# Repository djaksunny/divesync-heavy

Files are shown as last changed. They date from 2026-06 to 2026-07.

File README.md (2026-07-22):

# DiveSync Heavy

An autonomous underwater depth-control vehicle built around an ESP32 and MS5837 depth sensor, using a linear actuator syringe mechanism (0–100mm stroke) for buoyancy-based depth control. This repo contains the firmware, hardware design files, and control software — including PID and reinforcement learning (TD3) controllers — developed as part of ongoing research under Umar.

## Hardware Overview

- **Depth sensing:** MS5837 pressure/depth sensor
- **Actuation:** Linear actuator-driven syringe mechanism, 0–100mm stroke, adjusts buoyancy by changing displaced volume
- **Compute:** ESP32, communicating over USB serial (115200 baud) with a host machine running the Python control stack
- **Control loop:** 20Hz telemetry/state/actuator loop, with an inner PID stabilizing actuator position and an outer controller (PID / BC / RL) setting the depth-tracking target

Full schematics, PCB layout, and BOM are under `/eda`.

## Repository Structure

```
divesync-heavy/
├── data/                     # Raw experiment logs, grouped by hardware/software version -- see "Experiment Data" below
├── eda/                      # KiCad schematic, PCB, BOM, and exported schematic PDF
├── firmware/                 # ESP32 firmware (PlatformIO project)
├── python/
│   ├── controllers/
│   │   ├── inner.py           # Inner PID loop — actuator position control
│   │   ├── manual.py          # Gamepad/keyboard manual control
│   │   ├── pid.py             # Outer PID depth controller
│   │   ├── rl.py              # TD3 (fully online) depth controller
│   │   └── waveform.py        # Square-wave setpoint/actuator generator
│   ├── core/
│   │   ├── experiment.py      # Experiment setup, handshake, state machine
│   │   ├── logger.py          # CSV logging (raw/processed/state)
│   │   ├── merger.py          # Merges state + processed CSVs into training_data.csv
│   │   ├── processor.py       # Depth filtering, actuator unit conversion
│   │   ├── serial_manager.py  # Serial I/O with the ESP32
│   │   ├── state.py           # Computes depth error, filtered velocity
│   │   └── telemetry.py       # Raw serial line parsing
│   ├── ml/
│   │   ├── reward.py              # TD3 reward function
│   │   ├── td3_env_spec.py        # Gym shape-declaration env for SB3 (also defines the fixed obs-normalization bounds)
│   │   ├── td3_model.zip          # Actively-training TD3 model (updated after each RL dive)
│   │   └── td3_replay_buffer.pkl  # Persisted replay buffer across dives
│   └── visualization/
│       ├── display.py         # Live Tkinter depth/setpoint/error display
│       └── plotter.py         # Post-dive matplotlib plotting (depth/actuator/motor voltage)
├── results/
│   ├── divesync-heavy-v1-results/   # Behavior cloning, cascaded PID, step response, sysid plots
│   ├── divesync-heavy-v2-results/   # Behavior cloning, cascaded PID (fixed/variable), RL (fixed/variable)
│   └── divesync-heavy-v3-results/   # Fully-online RL: early / failure / converged
├── main.py                    # Experiment entry point / main control loop
├── requirements.txt
├── .gitignore
└── README.md
```

## Control Strategies

Two outer-loop control strategies were implemented and compared:

1. **PID** — classical outer-loop depth PID feeding actuator position setpoints to the inner PID. Cascaded/nested PID across both loops was tested and found unstable (~99% of trials); the current architecture uses a single outer PID plus a fixed inner actuator-position PID instead.
2. **Reinforcement Learning (TD3)** — an off-policy, deterministic actor-critic algorithm (Twin Delayed DDPG), trained fully online on real hardware from a randomly-initialized actor and critics (no warm-start). Chosen over SAC/PPO/DDPG because its replay buffer suits the limited real-hardware sample budget, and its twin critics counter the Q-value overestimation that made vanilla DDPG unreliable.

### TD3 Implementation Notes

- Built on `stable_baselines3` (Gymnasium 1.3.0 / SB3 2.9.0), with a shape-only `DiveSyncEnvSpec` env used purely to satisfy SB3's constructor — no vectorized-env training loop is used. `main.py`'s own 20Hz loop *is* the environment loop; each dive is treated as one training episode.
- State inputs to the actor are normalized using the fixed bounds declared in `DiveSyncEnvSpec` (`OBS_LOW`/`OBS_HIGH`), not a data-fitted scaler.
- The reward function combines a depth-tracking error penalty, a velocity-damping penalty, and a smooth exponential barrier discouraging surfacing (and, in later iterations, an analogous barrier for the tank floor and an action-delta smoothness penalty).
- Both online (small periodic updates during a dive) and end-of-dive (`finalize()`, larger update) training were implemented; see **Known Issues** below regarding online training stability.
- Reward isn't logged during a dive. `python/reward_backfill.py` (gitignored, not part of the tracked pipeline) computes it after the fact from a run's `state.csv` (`depth_error_m`, `velocity_mps`) using the weights currently defined in `controllers/rl.py`, across every RL experiment under `data/` at once, writing a gitignored `reward.csv` / `reward_plot.png` per folder. Intent going forward is for `visualization/plotter.py` to compute this the same way but on the fly for a single experiment, rather than relying on a separate batch pass — not wired up yet.

## Running an Experiment

```bash
pip install -r requirements.txt
python main.py
```

You'll be prompted for:
- **Control mode:** `manual` / `pid` / `rl` / `sysid`
- **Experiment duration** (seconds)
- **Notes** (optional, stored in `metadata.json`)
- **COM port** for the ESP32

Each run creates a timestamped folder under `data/` containing `raw.csv`, `processed.csv`, `state.csv`, `boot.txt`, and `metadata.json`. After the experiment ends, `training_data.csv` is generated (merging `state.csv` and `processed.csv`), and a results plot is shown automatically if `processed.csv` exists.

The first `rl`-mode run initializes a fresh TD3 model (random actor + critics) since there is no warm-start; `python/ml/td3_model.zip` and `td3_replay_buffer.pkl` are created after `finalize()` and reused/extended on subsequent RL dives.

## Known Issues / Future Work

- **Online (mid-dive) training instability:** periodic training updates during a dive were found to occasionally collapse the policy into a degenerate constant-action output, likely due to the critic training on too little, too-correlated data early in a dive. Online training is currently disabled by default (`online_gradient_steps=0`); all TD3 updates happen in `finalize()`, once per dive. This was directly reproduced on the first fully-online (no warm-start) dive: the policy overshot to the tank floor, recovered, then froze at a near-constant near-minimum actuator output for the remaining ~9 minutes of a ~11-minute dive despite a large, persistent tracking error. `RLController` now has a `random_warmup_decisions` phase (default 50 decisions, ~50s) where actions are sampled randomly (still delta-clamped for hardware safety) instead of drawn from the untrained actor, so the critic sees diverse transitions before any training happens.
- **Reward scale sensitivity:** TD3 training was found to be highly sensitive to reward term magnitudes — a ~40x increase in one reward weight relative to another was sufficient to destabilize training into bang-bang actuator behavior. Current weights are tuned empirically; a more principled reward-normalization approach is a natural next step.
- **Residual steady-state tracking error:** the current TD3 policy shows a repeatable damped-oscillation response to setpoint changes, converging to a small but consistent depth offset rather than exact tracking. Believed limited primarily by the small amount of real-dive training data available; a larger and more diverse replay buffer (more dives, more setpoint variety) is the most likely path to improvement.

## Experiment Data

Raw experiment logs under `data/`, grouped to match the hardware/software progression documented in `/results`. Each leaf folder is one experiment run (`YYYYMMDD-HHMMSS`), containing `raw.csv`, `processed.csv`, `state.csv`, `boot.txt`, `metadata.json`, and (once merged) `training_data.csv`.

### `divesync-heavy-v1-data/` (2026-07-06 -- 2026-07-09, 14 dives)

Earliest hardware iteration (50mm actuator stroke). Manual piloting, initial PID characterization, step-response/system-ID runs, and the first behavior-cloning + BC-warmstarted-RL attempts. Corresponds to `results/divesync-heavy-v1-results/`.

### `divesync-heavy-v2-data/` (2026-07-10, 2026-07-14, 31 dives)

100mm actuator stroke. Manual piloting for BC training data, PID validation (fixed/variable setpoint), and BC-pretraining-warmstarted TD3 -- the warmstart approach later found to underperform and replaced in v3. Corresponds to `results/divesync-heavy-v2-results/`.

### `divesync-heavy-v3-data/` -- fully-online TD3, no BC warm-start

The BC/warmstart pipeline was removed; TD3 trains entirely online from real dives from here on. Corresponds to `results/divesync-heavy-v3-results/` (reinforcement-learning-early/failure/converged). Split into three subfolders:

- **`pid-validation/`** (2026-07-16, 11 dives) -- pure PID control-mode dives, re-validating the classical baseline on this hardware revision before RL work resumed.
- **`pre-swap/`** (2026-07-17, 23 dives) -- first fully-online TD3 dives on this hardware. Includes the full progression from cold-start collapse through the stuck-recovery and velocity-penalty fixes; best sustained result is `20260717-161502` (81% of samples within 0.05m of setpoint over a 10-minute dive).
- **`post-swap/`** (2026-07-21 -- 2026-07-22, 15 dives) -- after the actuator/buoyancy device was physically swapped, changing the depth dynamics enough to require a model reset (the pre-swap model/replay buffer no longer matched reality -- see `divesync-heavy-v3-data-incomplete-runs/README` for how that was diagnosed). Training restarted fully online on this dataset, converging faster than the original cold start since the warmup/stuck-recovery/reward fixes were already in place.

**Note for reuse:** `pre-swap` and `post-swap` reflect two physically different dynamical systems (same v3 software/methodology, different hardware buoyancy characteristics). Don't pool them for a single tracking-accuracy statistic without accounting for that split.

### `divesync-heavy-v3-data-incomplete-runs/`

Crashed/aborted experiments with no meaningful data (empty or header-only CSVs, no `metadata.json`) -- kept rather than deleted in case they're ever useful for debugging, but excluded from all of the above.

## Results

Comparison plots (behavior cloning, cascaded/fixed/variable PID, fixed/variable-setpoint RL, system identification, step response) are in `/results` and `/results/divesync-heavy-v1-results`.

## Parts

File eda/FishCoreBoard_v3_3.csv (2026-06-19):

Reference | Value | Footprint | Qty | DNP | Label | Part
C1,C3 | 100nF | Capacitor_SMD:C_1206_3216Metric | 2 |  |  | C1206C104K4RAC7800
C2,C4,C5,C7 | 10uF | Capacitor_SMD:C_1206_3216Metric | 4 |  |  | C1206C106K4RAC7800
C6,C12 | 220uF | Capacitor_SMD:CP_Elec_6.3x4.5,Capacitor_SMD:C_1206_3216Metric | 2 |  |  | A768EB476M1ELAE042,C1206C106K4RAC7800
C9 | 470uF | Capacitor_SMD:CP_Elec_6.3x4.5 | 1 |  |  | 875585345004
C10,C11 | 47uF | Capacitor_SMD:CP_Elec_6.3x4.5 | 2 |  |  | A768EB476M1ELAE042
D13 | B340AE-13 | Diode_SMD:D_SMA | 1 |  |  | B340AE-13
J1,J3,J4 | B2B_XH | Connector_JST:JST_XH_B2B-XH-A_1x02_P2.50mm_Vertical | 3 |  | - PWR +,MOT,SW | B2B-XH-A
J2 | Conn_01x05_Pin | Connector_JST:JST_XH_B5B-XH-A_1x05_P2.50mm_Vertical | 1 |  | SYG_ACT | B5B-XH-A
J5 | Conn_01x03_Pin | Connector_JST:JST_XH_B3B-XH-A_1x03_P2.50mm_Vertical | 1 |  | SERVO | B3B-XH-A
J6 | BM04BGHS | Connector_JST:JST_GH_BM04B-GHS-TBT_1x04-1MP_P1.25mm_Vertical | 1 |  | BAR02 | BM04B-GHS-TBT
J7 | Conn_01x04_Pin | Connector_JST:JST_PH_B4B-PH-K_1x04_P2.00mm_Vertical | 1 |  | + R T - | B4B-PH-K
L1 | 68uH | Inductor_SMD:L_Coilcraft_MSS1048-XXX | 1 |  |  | MSS1048-683MLC
R1,R2,R4,R6 | 2K2 | Resistor_SMD:R_1206_3216Metric | 4 |  |  | RMCF1206JT2K20
R3 | 4K7 | Resistor_SMD:R_1206_3216Metric | 1 |  |  | RMCF1206JT4K70
R5 | 1K5 | Resistor_SMD:R_1206_3216Metric | 1 |  |  | RMCF1206JT1K50
RV1 | R_Potentiometer | Potentiometer_SMD:Potentiometer_Bourns_3214J_Horizontal | 1 |  |  | 3314J-1-103E
U1,U3 | DRV8251ADDAR | Umar_Library:SOIC8_DDA_TEX | 2 |  |  | DRV8251ADDAR
U2 | ESP32-C3-DEVKITC-02 | Umar_Library:XCVR_ESP32-C3-DEVKITC-02 | 1 |  |  | ESP32-C3-DEVKITC-02
U5 | AMS1117-3.3 | Package_TO_SOT_SMD:SOT-223-3_TabPin2 | 1 |  |  | AMS1117-3.3
U6 | LM2596S-ADJ | Package_TO_SOT_SMD:TO-263-5_TabPin3 | 1 |  |  | LM2596S-ADJ/NOPB
U7 | AMS1117-5.0 | Package_TO_SOT_SMD:SOT-223-3_TabPin2 | 1 |  |  | AMS1117-5.0

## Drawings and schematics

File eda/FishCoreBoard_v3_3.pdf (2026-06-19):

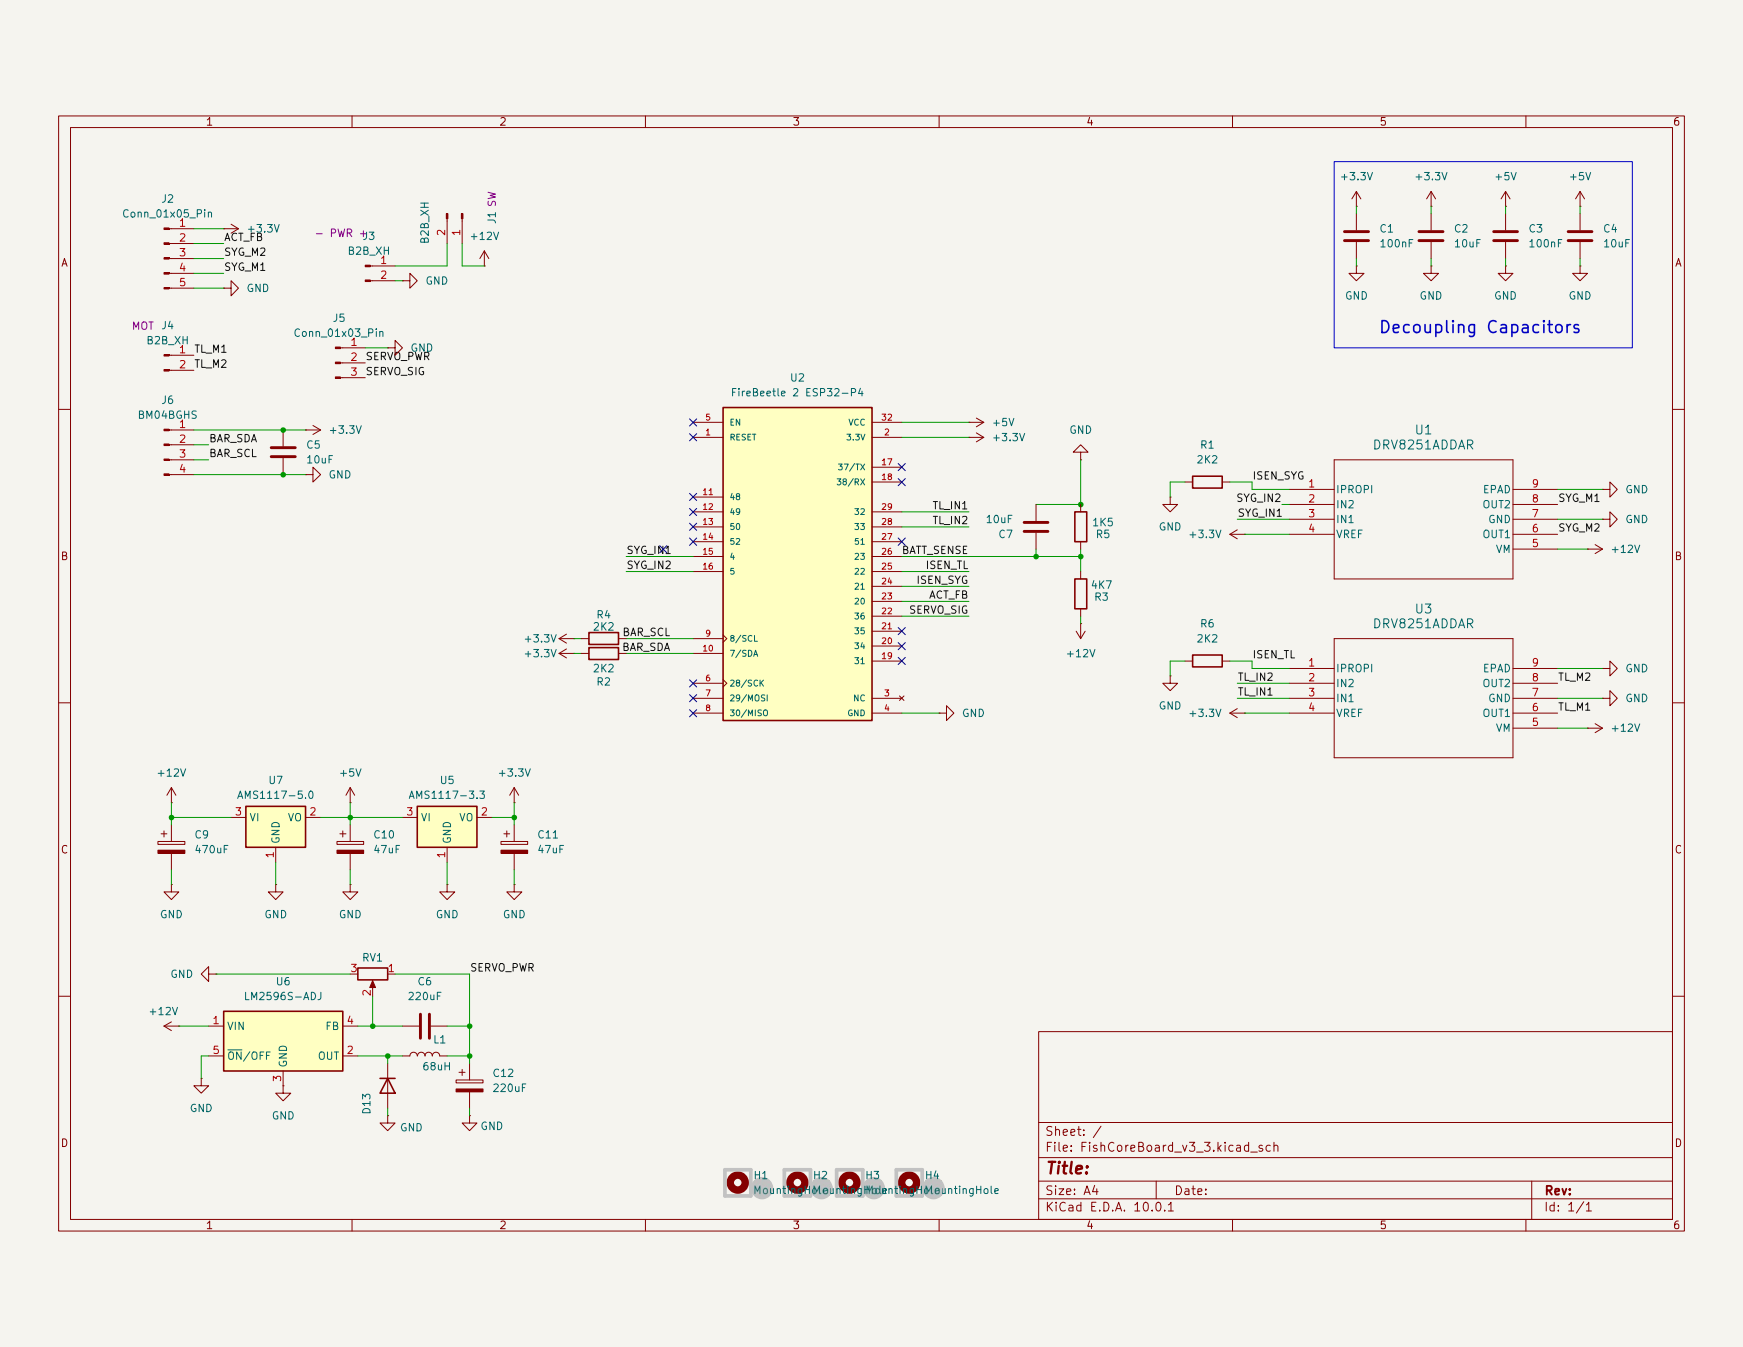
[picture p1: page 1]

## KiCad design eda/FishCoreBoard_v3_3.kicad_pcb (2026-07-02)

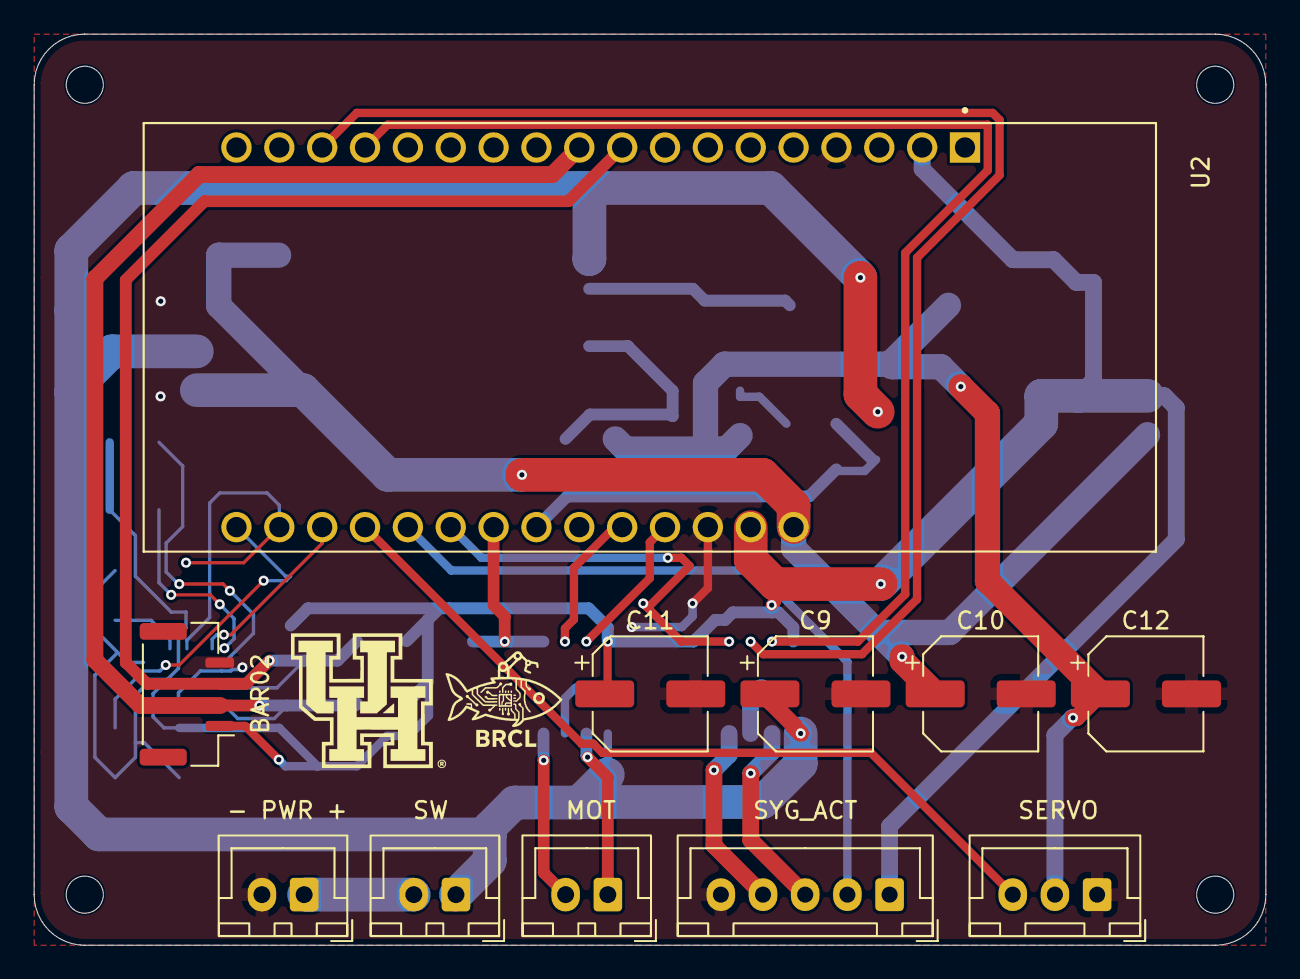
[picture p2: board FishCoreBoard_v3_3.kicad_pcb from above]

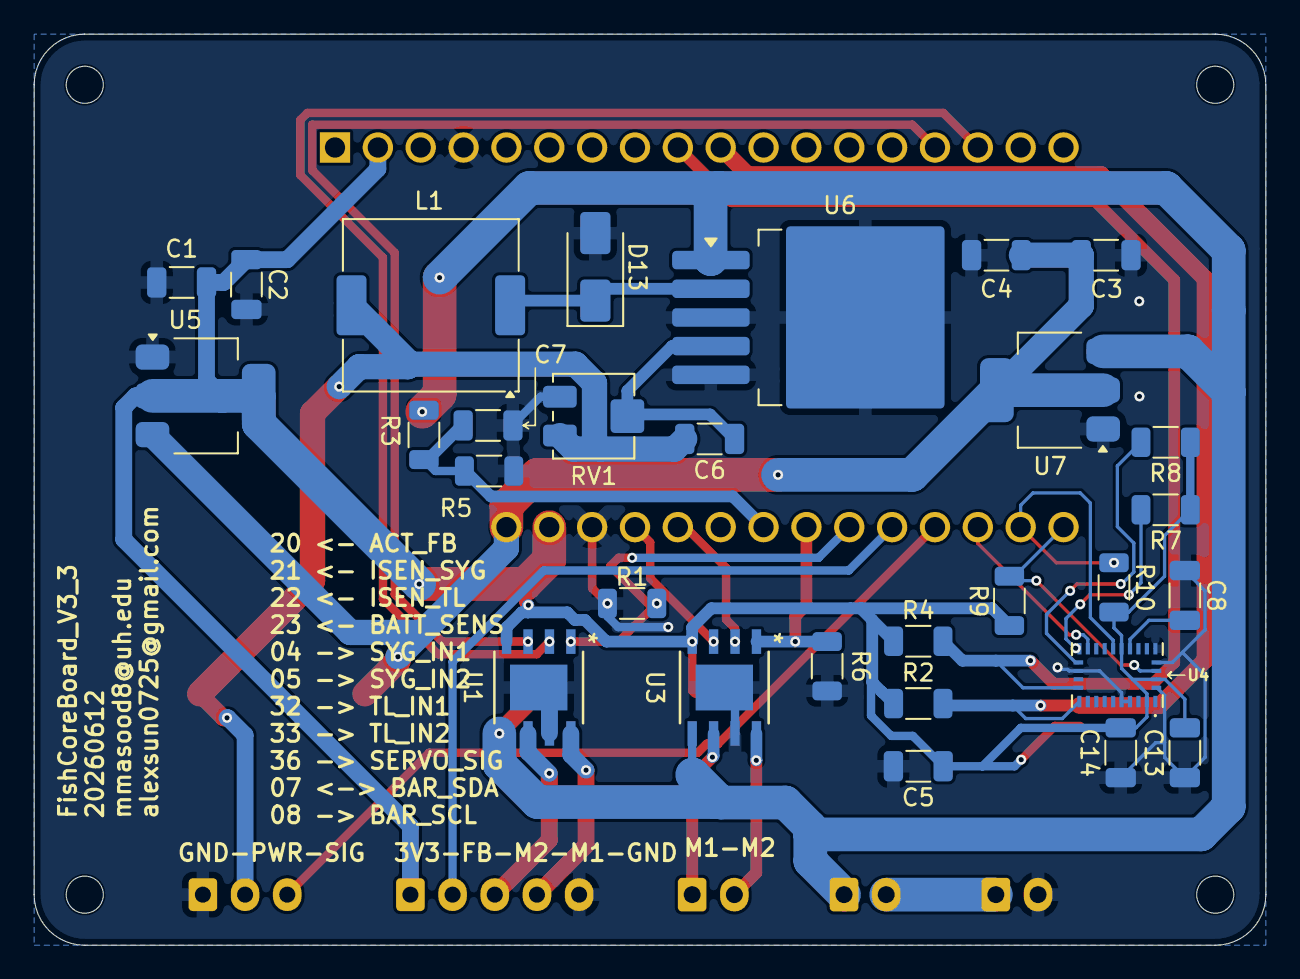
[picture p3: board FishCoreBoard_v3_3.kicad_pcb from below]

Board: 2 copper layers, 73.0 x 54.0 mm, 44 parts (29 on the bottom side), 29 nets.

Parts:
C1, C3, C8, C13, C14: 100nF; C_1206_3216Metric
C2, C4, C5, C7: 10uF; C_1206_3216Metric
C6: 220uF; C_1206_3216Metric
C9: 470uF; CP_Elec_6.3x4.5
C10, C11: 47uF; CP_Elec_6.3x4.5
C12: 220uF; CP_Elec_6.3x4.5
D13: B340AE-13; D_SMA
H1, H2, H3, H4: MountingHole; MountingHole_2.2mm_M2
J1, J3, J4: B2B_XH; JST_XH_B2B-XH-A_1x02_P2.50mm_Vertical
J2: Conn_01x05_Pin; JST_XH_B5B-XH-A_1x05_P2.50mm_Vertical
J5: Conn_01x03_Pin; JST_XH_B3B-XH-A_1x03_P2.50mm_Vertical
J6: BM04BGHS; JST_GH_BM04B-GHS-TBT_1x04-1MP_P1.25mm_Vertical
L1: 68uH; L_Coilcraft_MSS1048-XXX
R1, R2, R4, R6: 2K2; R_1206_3216Metric
R3: 4K7; R_1206_3216Metric
R5: 1K5; R_1206_3216Metric
R7, R8, R9, R10: 10kΩ; R_1206_3216Metric
RV1: R_Potentiometer; Potentiometer_Bourns_3214J_Horizontal
U1, U3: DRV8251ADDAR; SOIC8_DDA_TEX
U2: FireBeetle 2 ESP32-P4; MODULE_DFR0654
U4: BNO086; IC_BNO086
U5: AMS1117-3.3; SOT-223-3_TabPin2
U6: LM2596S-ADJ; TO-263-5_TabPin3
U7: AMS1117-5.0; SOT-223-3_TabPin2

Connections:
+3.3V: C1.1, C2.1, C5.1, C11.1, C13.2, C14.2, J2.1, J6.1, R2.1, R4.1, R7.1, R8.1, R9.1, R10.2, U1.4 (VREF), U2.2 (3.3V), U2.31 (3.3V), U3.4 (VREF), U4.3 (VDD), U4.10 (CLKSEL0), U4.28 (VDDIO), U5.2 (VO)
+5V: C3.1, C4.1, C10.1, U2.32 (VCC), U5.3 (VI), U7.2 (VO)
+12V: C9.1, J1.1, R3.1, U1.5 (VM), U3.5 (VM), U6.1 (VIN), U7.3 (VI)
/ACT_FB: J2.2, U2.23 (20)
/BATT_SENSE: C7.1, R3.2, R5.1, U2.26 (23)
/IMU_BOOT: R9.2, U2.19 (31), U4.4 (~BOOT)
/IMU_INT: U2.21 (35), U4.14 (~H_INT)
/IMU_RST: R10.1, U2.20 (34), U4.11 (~RST)
/ISEN_SYG: R1.2, U1.1 (IPROPI), U2.24 (21)
/ISEN_TL: R6.2, U2.25 (22), U3.1 (IPROPI)
/SCL: J6.3, R4.2, U2.9 (8/SCL), U4.19 (H_SCL/SCK/RX)
/SDA: J6.2, R2.2, U2.10 (7/SDA), U4.20 (H_SDA/H_MISO/TX)
/SERVO_PWR: C6.2, C12.1, J5.2, L1.2, RV1.1
/SERVO_SIG: J5.3, U2.22 (36)
/SYG_IN1: U1.3 (IN1), U2.15 (4)
/SYG_IN2: U1.2 (IN2), U2.16 (5)
/SYG_M1: J2.4, U1.8 (OUT2)
/SYG_M2: J2.3, U1.6 (OUT1)
/TL_IN1: U2.29 (32), U3.3 (IN1)
/TL_IN2: U2.28 (33), U3.2 (IN2)
/TL_M1: J4.1, U3.6 (OUT1)
/TL_M2: J4.2, U3.8 (OUT2)
GND: C1.2, C2.2, C3.2, C4.2, C5.2, C7.2, C8.1, C9.2, C10.2, C11.2, C12.2, C13.1, C14.1, D13.2 (A), J2.5, J3.2, J5.1, J6.4, R1.1, R5.2, R6.1, RV1.3, U1.7 (GND), U2.4 (GND), U2.30 (GND), U3.7 (GND), U4.2 (GND), U4.5 (PS1), U4.6 (PS0/WAKE), U4.17 (SA0/H_MOSI), U4.25 (GNDIO), U4.26 (XOUT32/CLKSEL1), U5.1 (GND), U6.3 (GND), U6.5 (~ON/OFF), U7.1 (GND)
unnamed: D13.1 (K), L1.1, U6.2 (OUT)
unnamed: J1.2, J3.1
unnamed: C8.2, U4.9 (CAP)
unnamed: R7.2, U4.15 (ENV_SCL)
unnamed: R8.2, U4.16 (ENV_SDA)
unnamed: C6.1, RV1.2, U6.4 (FB)

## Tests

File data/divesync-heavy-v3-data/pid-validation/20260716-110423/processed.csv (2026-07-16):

time_s | actuator_mm | actuator_setpoint_mm | depth_filtered_m | depth_setpoint_m | motor_cmd
0.352 | 47.179 | 49.01275160000002 | 0.1227 | 0.5791 | 0.0
0.401 | 47.204 | 49.01275160000002 | 0.1227 | 0.5791 | 0.0
0.451 | 47.277 | 49.0624992000002 | 0.1227 | 0.5791 | 7.764705882352941
0.501 | 47.155 | 49.0624992000002 | 0.1227 | 0.5791 | 7.764705882352941
0.551 | 47.57 | 49.11645789787256 | 0.1225 | 0.5791 | 7.7176470588235295
0.601 | 47.888 | 49.11645789787256 | 0.1225 | 0.5791 | 7.7176470588235295
0.651 | 48.449 | 49.148740000000245 | 0.1225 | 0.5791 | 7.623529411764705
0.701 | 48.449 | 49.160507767742104 | 0.1227 | 0.5791 | 7.623529411764705
0.751 | 48.938 | 49.160507767742104 | 0.1227 | 0.5791 | 7.341176470588235
0.801 | 48.864 | 49.21953840000022 | 0.1227 | 0.5791 | 7.341176470588235
0.851 | 48.913 | 49.21953840000022 | 0.1227 | 0.5791 | 7.152941176470589
0.901 | 49.377 | 49.25691145106408 | 0.1228 | 0.5791 | 7.152941176470589
0.951 | 49.451 | 49.29052120000019 | 0.1228 | 0.5791 | 7.152941176470589
1.001 | 49.475 | 49.29052120000019 | 0.1228 | 0.5791 | 7.152941176470589
1.051 | 49.499 | 49.33341340000022 | 0.1228 | 0.5791 | -7.105882352941176
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

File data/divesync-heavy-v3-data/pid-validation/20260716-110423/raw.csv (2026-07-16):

time_ms | actuator_raw | motor_cmd | depth_m | pressure_mbar | temp_c | depth_ok | battery_v
352 | 1932 | 0 | 0.1227 | 1025.03 | 22.45 | 1 | 12.53
401 | 1933 | 0 | 0.1227 | 1025.03 | 22.51 | 1 | 12.53
451 | 1936 | 165 | 0.1225 | 1025.01 | 22.55 | 1 | 12.51
501 | 1931 | 165 | 0.1224 | 1025.00 | 22.57 | 1 | 12.50
551 | 1948 | 164 | 0.1224 | 1025.00 | 22.59 | 1 | 12.51
601 | 1961 | 164 | 0.1223 | 1024.99 | 22.60 | 1 | 12.51
651 | 1984 | 162 | 0.1228 | 1025.04 | 22.61 | 1 | 12.53
701 | 1984 | 162 | 0.1233 | 1025.09 | 22.61 | 1 | 12.50
751 | 2004 | 156 | 0.1236 | 1025.12 | 22.62 | 1 | 12.50
801 | 2001 | 156 | 0.1242 | 1025.18 | 22.63 | 1 | 12.51
851 | 2003 | 152 | 0.1242 | 1025.18 | 22.63 | 1 | 12.53
901 | 2022 | 152 | 0.1238 | 1025.14 | 22.63 | 1 | 12.50
951 | 2025 | 152 | 0.1239 | 1025.15 | 22.63 | 1 | 12.50
1001 | 2026 | 152 | 0.1228 | 1025.04 | 22.63 | 1 | 12.50
1051 | 2027 | -151 | 0.1224 | 1025.00 | 22.63 | 1 | 12.53
1101 | 2014 | -151 | 0.1225 | 1025.01 | 22.64 | 1 | 12.50
1151 | 2053 | -151 | 0.1221 | 1024.97 | 22.63 | 1 | 12.50
1201 | 2021 | -151 | 0.1225 | 1025.01 | 22.64 | 1 | 12.51
1251 | 2003 | -156 | 0.1228 | 1025.04 | 22.64 | 1 | 12.53
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

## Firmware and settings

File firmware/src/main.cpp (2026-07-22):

#include <Arduino.h>
#include <Wire.h>
#include <MS5837.h>

// =========================
// Pin definitions
// =========================
#define SYG_IN1     4
#define SYG_IN2     5
#define SYG_FB      0       // Potentiometer feedback (analog in)
#define BAR_SDA     19
#define BAR_SCL     18
#define BATT_SENSE  3

// =========================
// Actuator limits
// =========================
#define SYG_MAX 4050        // Safe upper travel limit
#define SYG_MIN 400         // Safe lower travel limit

// =========================
// PWM settings (LEDC)
// =========================
#define PWM_FREQ    25000   // 25 kHz: above human hearing to eliminate whine
#define PWM_RES     8       // 8-bit resolution (0-255)
#define PWM_CH1     0       // LEDC hardware channel for IN1
#define PWM_CH2     1       // LEDC hardware channel for IN2

// =========================
// General settings
// =========================
#define NUM_SAMPLES_ACTUATOR        10
#define SERIAL_BAUD                 115200
#define TELEMETRY_PERIOD_MS         50
#define ATM_PRESSURE_MBAR           1024
#define DEPTH_SENSOR_REQUIRED       true

// =========================
// Battery ADC calibration
// =========================
#define ADC_MAX_COUNTS              4095.0f
#define ADC_REF_VOLTAGE             3.3f
#define BATT_DIVIDER_R_TOP_OHM      20000.0f
#define BATT_DIVIDER_R_BOTTOM_OHM   1500.0f

// =========================
// Fluid density
// =========================
const int FLUID_DENSITY = 1000;  // kg/m^3

// =========================
// Global state
// =========================
MS5837 BAR;

volatile int  g_motor_cmd      = 0;
unsigned long g_last_telemetry = 0;
bool          g_depth_ok       = false;

// =========================
// Function declarations
// =========================
int   getActuator(int n = NUM_SAMPLES_ACTUATOR);
void  actuate(int u);
void  processSerial();
void  sendTelemetry();
bool  updateDepthSensor(float &pressure_mbar, float &temperature_c, float &depth_m);
int   clampMotorCommand(int u);
float readBatteryVoltage();

// =========================
// Setup
// =========================
void setup() {
    pinMode(SYG_FB,     INPUT);
    pinMode(BATT_SENSE, INPUT);
    analogReadResolution(12);
    analogSetPinAttenuation(BATT_SENSE, ADC_0db);

    Serial.begin(SERIAL_BAUD);
    delay(200);

    // LEDC PWM init
    ledcSetup(PWM_CH1, PWM_FREQ, PWM_RES);
    ledcSetup(PWM_CH2, PWM_FREQ, PWM_RES);
    ledcAttachPin(SYG_IN1, PWM_CH1);
    ledcAttachPin(SYG_IN2, PWM_CH2);
    actuate(0);  // Brake on startup

    // Depth sensor init — blocks until ready if DEPTH_SENSOR_REQUIRED
    Wire.begin(BAR_SDA, BAR_SCL);

    do {
        if (BAR.init()) {
            BAR.setModel(MS5837::MS5837_02BA);
            BAR.setFluidDensity(FLUID_DENSITY);
            g_depth_ok = true;
            Serial.println("DEPTH_SENSOR_OK");
            break;
        }

        g_depth_ok = false;
        Serial.println("DEPTH_SENSOR_FAIL");

        if (DEPTH_SENSOR_REQUIRED) {
            Serial.println("WAITING_FOR_DEPTH_SENSOR");
            delay(500);
        }
    } while (DEPTH_SENSOR_REQUIRED);

    Serial.println("LOW_LEVEL_DEPTH_ACTUATOR_INTERFACE_READY");
}

// =========================
// Main loop
// =========================
void loop() {
    processSerial();
    actuate(g_motor_cmd);

    if (millis() - g_last_telemetry >= TELEMETRY_PERIOD_MS) {
        g_last_telemetry = millis();
        sendTelemetry();
    }
}

// =========================
// Serial command handling
// =========================
void processSerial() {
    if (!Serial.available()) return;

    String msg = Serial.readStringUntil('\n');
    msg.trim();
    if (msg.length() == 0) return;

    if (msg == "R") {
        sendTelemetry();
        return;
    }

    if (msg == "S") {
        g_motor_cmd = 0;
        actuate(0);
        Serial.println("ACK:STOP");
        return;
    }

    if (msg.startsWith("U:")) {
        int cmd = msg.substring(2).toInt();
        g_motor_cmd = clampMotorCommand(cmd);
        Serial.print("ACK:U:");
        Serial.println(g_motor_cmd);
        return;
    }

    if (msg == "RST") {
        ESP.restart();
    }

    Serial.print("ERR:UNKNOWN_CMD:");
    Serial.println(msg);
}

// =========================
// Telemetry output
// =========================
void sendTelemetry() {
    int   act_raw   = getActuator();
    float battery_v = readBatteryVoltage();

    float pressure_mbar = NAN;
    float temperature_c = NAN;
    float depth_m       = NAN;

    bool ok = updateDepthSensor(pressure_mbar, temperature_c, depth_m);

    // CSV: time_ms, actuator_raw, motor_cmd, depth_m, pressure_mbar, temp_c, depth_ok, battery_v
    Serial.print(millis());         Serial.print(",");
    Serial.print(act_raw);          Serial.print(",");
    Serial.print(g_motor_cmd);      Serial.print(",");
    Serial.print(depth_m, 4);       Serial.print(",");
    Serial.print(pressure_mbar, 2); Serial.print(",");
    Serial.print(temperature_c, 2); Serial.print(",");
    Serial.print(ok ? 1 : 0);       Serial.print(",");
    Serial.println(battery_v, 2);
}

// =========================
// Battery voltage read
// =========================
float readBatteryVoltage() {
    float v_sense     = analogReadMilliVolts(BATT_SENSE);
    float divider_gain = (BATT_DIVIDER_R_TOP_OHM + BATT_DIVIDER_R_BOTTOM_OHM)
                         / BATT_DIVIDER_R_BOTTOM_OHM;
    return v_sense * divider_gain / 1000.0f;
}

// =========================
// Depth sensor update
// =========================
bool updateDepthSensor(float &pressure_mbar, float &temperature_c, float &depth_m) {
    if (!g_depth_ok) return false;

    BAR.read();
    pressure_mbar = BAR.pressure();
    temperature_c = BAR.temperature();
    depth_m       = BAR.depth();

    return !(isnan(pressure_mbar) || isnan(temperature_c) || isnan(depth_m));
}

// =========================
// Actuator drive (DRV8251 via LEDC)
// =========================
void actuate(int u) {
    int pos = analogRead(SYG_FB);

    // Hard software travel limits
    if (pos >= SYG_MAX && u > 0) u = 0;
    if (pos <= SYG_MIN && u < 0) u = 0;

    u = constrain(u, -255, 255);

    if (u > 0) {                    // Extend
        ledcWrite(PWM_CH1, 0);
        ledcWrite(PWM_CH2, u);
    } else if (u < 0) {             // Retract
        ledcWrite(PWM_CH2, 0);
        ledcWrite(PWM_CH1, -u);
    } else {                        // Brake: both inputs HIGH
        ledcWrite(PWM_CH1, 255);
        ledcWrite(PWM_CH2, 255);
    }
}

// =========================
// Read actuator position (averaged)
// =========================
int getActuator(int n) {
    int sum = 0;
    for (int i = 0; i < n; i++) {
        sum += analogRead(SYG_FB);
    }
    return sum / n;
}

// =========================
// Clamp command to valid range
// =========================
int clampMotorCommand(int u) {
    return constrain(u, -255, 255);
}

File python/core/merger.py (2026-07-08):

import json
import sys
import pandas as pd
from pathlib import Path


class Merger:
    def __init__(self, folder_path):
        self._folder_path = folder_path
        self._state_path = Path(folder_path) / "state.csv"
        self._processed_path = Path(folder_path) / "processed.csv"

    def merge(self):
        if not self._state_path.exists():
            raise FileNotFoundError(f"'state.csv' not found inside {self._folder_path}")
        if not self._processed_path.exists():
            raise FileNotFoundError(f"'processed.csv' not found inside {self._folder_path}")

        state = pd.read_csv(self._state_path)
        proc = pd.read_csv(self._processed_path)

        state.dropna(how="all", inplace=True)
        proc.dropna(how="all", inplace=True)

        # Only pull actuator/motor fields from processed -- state stays the
        # source of truth for depth/error/velocity (what a live policy sees).
        merged = state.merge(
            proc[["time_s", "actuator_setpoint_mm"]],
            on="time_s",
            how="inner"
        )

        out_path = Path(self._folder_path) / "training_data.csv"
        merged.to_csv(out_path, index=False)

        return merged, out_path


if __name__ == "__main__":
    # Map target path to relative directory
    data_dir = Path("data")

    if not data_dir.exists() or not data_dir.is_dir():
        print("Error: The 'data' directory does not exist.\n")
        sys.exit(1)

    print("=== DIVESYNC HEAVY - TRAINING DATA MERGE INTERFACE ===\n")

    print("Available experiments:\n")

    # Gather available folders
    folder_list = sorted([str(f) for f in data_dir.iterdir() if f.is_dir()])

    def get_notes(folder):
        metadata_path = Path(folder) / "metadata.json"
        if not metadata_path.exists():
            return ""
        try:
            with open(metadata_path, "r") as f:
                metadata = json.load(f)
            return metadata.get("notes", "")
        except (json.JSONDecodeError, OSError):
            return ""

    # Display available choices in terminal
    for idx, folder in enumerate(folder_list):
        notes = get_notes(folder)
        if notes:
            print(f"[{idx}] {Path(folder).name} - {notes}")
        else:
            print(f"[{idx}] {Path(folder).name}")
    print()

    selected_folder_path = None

    while True:
        try:
            if len(folder_list) == 0:
                print("No folders available. Exiting merger.\n")
                sys.exit(0)

            folder_index = int(input("Select a folder (index): ").strip())
            selected_folder_path = folder_list[folder_index]
            print(f"\nSelected folder path: {selected_folder_path}. Merging...\n")
            break

        except ValueError:
            print("Error: please enter a valid number\n")
        except IndexError:
            if len(folder_list) == 1:
                print("Error: enter 0")
            else:
                print(f"Error: enter a number between 0 and {len(folder_list) - 1}\n")

    # Merge execution
    try:
        merger = Merger(folder_path=selected_folder_path)
        merged_df, out_path = merger.merge()
        print(f"[MERGE COMPLETE] Wrote {len(merged_df)} rows to {out_path}")
    except FileNotFoundError as e:
        print(f"Error: {e}\n")

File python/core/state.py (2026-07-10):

import time

class State:
    def __init__(self, velocity_window=9):
        self.time_s = 0.0

        self.depth_m = 0.0
        self.depth_setpoint_m = 0.0
        self.depth_error_m = 0.0
        self.velocity_mps = 0.0

        self._last_time_s = None
        self._last_depth_m = None

        self._velocity_window = []
        self._VELOCITY_LIMIT = velocity_window  # odd number recommended for clean median

        self.state_csv = None

    @staticmethod
    def _fmt(x, digits=4):
        """Format a value for CSV, safely handling None."""
        return f"{round(x, digits)}" if x is not None else ""

    def update(self, pro):
        self.time_s = pro.time_s
        self.depth_m = pro.depth_filtered_m
        self.depth_setpoint_m = pro.depth_setpoint_m

        # Calculate depth error (only if we have both a setpoint and a depth reading)
        if self.depth_setpoint_m is not None and self.depth_m is not None:
            self.depth_error_m = self.depth_setpoint_m - self.depth_m
        else:
            self.depth_error_m = None

        # Calculate raw vertical velocity
        if self._last_time_s is None or self.depth_m is None or self._last_depth_m is None:
            velocity_raw = 0.0
        else:
            dt = self.time_s - self._last_time_s

            if dt > 0:
                velocity_raw = (self.depth_m - self._last_depth_m) / dt
            else:
                velocity_raw = 0.0

        # Median filter on velocity to reject sensor-quantization jitter
        self._velocity_window.append(velocity_raw)

        if len(self._velocity_window) > self._VELOCITY_LIMIT:
            self._velocity_window.pop(0)

        sorted_window = sorted(self._velocity_window)
        mid = len(sorted_window) // 2
        self.velocity_mps = sorted_window[mid]

        # Store current values for next update
        self._last_time_s = self.time_s
        self._last_depth_m = self.depth_m

        self.state_csv = (
            f"{self._fmt(self.time_s, 3)},"
            f"{self._fmt(self.depth_m)},"
            f"{self._fmt(self.depth_setpoint_m)},"
            f"{self._fmt(self.depth_error_m)},"
            f"{self._fmt(self.velocity_mps)}"
        )

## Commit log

2026-06-19 chore: organized PlatformIO and KiCad structure
    [FishCoreBoard_v3_3.csv, FishCoreBoard_v3_3.kicad_pcb, FishCoreBoard_v3_3.kicad_sch]
2026-06-20 feat: added PWM functionality for actuator (-255 to 255)
2026-06-20 feat: added PID for actuator with GUI showing the PWM and PID
2026-06-25 feat: reworked firmware constants and added cascaded PID/waveform support to GUI
    [main.cpp]
2026-06-25 feat: added serial data logger with raw CSV export and updated firmware to reset upon serial connect
    [raw.csv]
2026-06-25 fix: fully implemented JSON and added QoL and bug fixes
    [raw.csv]
2026-06-25 feat: updated logger and created manual gamepad control of PWM
2026-06-26 fix: fixed minor bugs regarding JSON formatting
    [raw.csv]
2026-06-26 chore: updated gitignore and cleaned up data
    [raw.csv]
2026-06-26 chore: organized structure and updated logger code
    [raw.csv]
2026-06-27 fix: updated experiment.py functions
    [experiment.py, serial_manager.py, telemetry.py]
2026-06-29 fix: tweaked print logic and implemented battery voltage safeguard
    [raw.csv]
2026-06-29 fix: updated main loop behavior to stop more accurately
    [experiment.py]
2026-06-29 feat: added processor and updated logger accordingly
    [raw.csv]
2026-06-29 chore: permanently untracked __pycache__ folders
    [raw.csv]
2026-06-29 feat: implemented processor fully
    [processed.csv, raw.csv]
2026-06-29 fix: updated rounding convention in processed actuator data
    [processor.py]
2026-06-30 feat: updated experiment to contain PID instead of MPC, created PID controller
    [processed.csv, raw.csv]
2026-06-30 fix: updated classes to accommodate future additions (outer PID)
    [processed.csv, raw.csv]
2026-07-01 chore: updated format and tweaked plotter
    [processed.csv, raw.csv]
2026-07-01 fix: updated logic throughout, bug fixes and waveform integration
    [processed.csv, raw.csv]
2026-07-01 fix: updated gains
    [processed.csv, raw.csv]
2026-07-02 feat: updated plotter to contain main function for individual plotting
    [processed.csv, raw.csv]
2026-07-02 feat: updated structure to have inner PID control
    [processed.csv, raw.csv]
2026-07-02 chore: removed old experiment data folders
    [processed.csv, raw.csv]
2026-07-02 chore: updated PCB silkscreen
    [FishCoreBoard_v3_3.kicad_pcb]
2026-07-03 fix: updated gains and added feedforward for actuator deadband
2026-07-05 feat: added sysid mode
    [processed.csv, raw.csv]
2026-07-06 feat: added depth (outer) PID loop logic
2026-07-06 fix: updated midpoint logic for cascaded PID and updated plotter
    [processed.csv, raw.csv]
2026-07-07 feat: updated plotter and display for enhanced GUI and data collection
    [processed.csv, raw.csv]
2026-07-07 chore: removed unnecessary random import from main
    [processed.csv, raw.csv]
2026-07-07 feat: collected data and updated dark titlebar display
    [processed.csv, raw.csv]
2026-07-07 feat: added state class
    [processed.csv, raw.csv, state.csv]
2026-07-08 feat: added merger
    [processed.csv, raw.csv, state.csv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]
2026-07-08 chore: began work on BC
    [processed.csv, raw.csv, state.csv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]
2026-07-09 feat: implemented BC and tested
    [processed.csv, raw.csv, state.csv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]
2026-07-09 chore: updated firmware
    [processed.csv, raw.csv]
2026-07-10 feat: switched to v2 hardware and retrained BC
    [processed.csv, raw.csv, state.csv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]
2026-07-10 feat: retrained BC for new data only
    [processed.csv, raw.csv, state.csv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]
2026-07-14 feat: RL completed
    [processed.csv, raw.csv, state.csv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]
2026-07-14 feat: semi-works, need to continue tuning
    [processed.csv, raw.csv, state.csv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]
2026-07-14 fix: formatted data JSON for consistency
    [processed.csv, raw.csv, state.csv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]
2026-07-14 feat: verified cascaded PID
    [processed.csv, raw.csv, state.csv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]
2026-07-14 fix: changed firmware fluid density
    [main.cpp]
2026-07-15 fix: removed sysid mode
    [experiment.py]
2026-07-15 fix: reorganized file structure
    [processed.csv, raw.csv, state.csv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]
2026-07-15 fix: updated voltage divider values in accordance with PCB
    [main.cpp]
2026-07-15 fix: tuned gains
    [processed.csv, raw.csv, state.csv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]
2026-07-16 fix: updated BC to take PID data
    [processed.csv, raw.csv, state.csv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]
2026-07-16 feat: collected PID training data
    [processed.csv, raw.csv, state.csv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]
2026-07-19 feat: added actuator setpoint to display
2026-07-19 chore: fixed typo
    [processed.csv, raw.csv, state.csv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]
2026-07-19 feat: fully-online TD3 (no BC warm-start), stuck-recovery, and today's dive logs
    [processed.csv, raw.csv, state.csv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]
2026-07-20 chore: removed broken experiment directories
    [processed.csv, raw.csv, state.csv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]
2026-07-20 fix: tracked TD3 model to resume training
    [backfill_notes.py]
2026-07-21 chore: fixed README.md formatting
    [processed.csv, raw.csv, state.csv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]
2026-07-21 chore: tweaked default params
    [processed.csv, raw.csv, state.csv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]
2026-07-22 fix: updated firmware travel limits
    [main.cpp]
2026-07-22 chore: rearranged experiment directories
    [processed.csv, raw.csv, state.csv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]
2026-07-22 chore: trained rl
    [processed.csv, raw.csv, state.csv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]
